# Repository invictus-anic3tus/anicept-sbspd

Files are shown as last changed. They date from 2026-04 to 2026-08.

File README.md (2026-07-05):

<div align="center">

  <h1>The Anicept SBSPD</h1>

  title image

  <h3>By Anicetus</h3>

  <p display="inline">

  <a href="https://creativecommons.org/licenses/by-nc/4.0/">
    </a> <a href="https://hackclub.com/">
    
  </a>

  </p>

  <h4>The Self Built Solder Paste Dispenser! Able to be mounted onto just about any 3D printer, this device adds a holder for a solder paste syringe, fully replacing the need to buy a solder stencil.</h4>
</div>

<sub>This work is licensed under a
[Creative Commons Attribution-NonCommercial 4.0 International License](https://creativecommons.org/licenses/by-nc/4.0/).
</sub>

## About

Hi! I'm Anicetus, and I love 3D printers and making custom hardware. Some of my favorite hardware to make is custom PCBs, namely the [Anicept Tempus](https://github.com/invictus-anic3tus/tempus), which often use very tiny SMD parts. The common choice is to go buy a solder stencil, which allows solder paste to be spread onto the PCB and easily reflowed. But stencils can get _expensive_. And, of course, they can only be used for one specific PCB! If your project needs a redesign, that means you need a whole new stencil for it.

So I got to thinking. Way back when, all plastic parts were made with injection molding, which had the same problems as solder stencils do now: to make a different plastic part, you need a whole new mold, which is very expensive. Then they invented 3D printers. These devices move in all three dimensions to make almost _any_ plastic part you want--why shouldn't the stencil problem have the same solution?

Well, maybe there is a good reason that this isn't so widespread. In any case, I'm about to find out.

## Features

- A Nema 11 stepper motor for accurate and high-power control over the solder syringe
- An easy-to-use clamp/hinge system that holds everything tightly in place
- A magnet-based mounting system that's compatable with any 3D printer
- Only four different screws/nuts!
- A fully 3D printable case
- A compact form factor
- ... all this for $15!

## Assembly + Usage

Assembly video coming soon! For now, please reference the CAD design to see how everything fits together :)







SBSPD_Wiring

## Bill of Materials

| Part | Link | Price  | Notes |
|---|---|---|---|
| Nema 11 | https://www.aliexpress.us/item/2255799884723806.html | $5.58  | 11HS3410 |
| Motor Driver | https://www.aliexpress.us/item/3256805074646808.html | $0.99  | TMC2209 |
| M5x50 SHCS | https://www.aliexpress.us/item/2255800598515019.html | $0.99  | For plunger + hinge |
| M2.5x16 SHCS | https://www.aliexpress.us/item/2255800598515019.html | $0.99  | For motor + clamp |
| M5 Nut | https://www.aliexpress.us/item/2255800416538696.html | $0.99  | For hinge + gear |
| M2.5 Nut | https://www.aliexpress.us/item/2255800416538696.html | $0.99  | For clamp |
| Magnets | https://www.aliexpress.us/item/3256809809310037.html | $0.99  | 4x2mm - required over ten for the PCB-bed mount standoffs |
| Adhesive | https://www.aliexpress.us/item/3256809785876209.html | $0.99  | For attaching the mount to the 3D printer |
| Solder Paste | https://www.amazon.com/SMD291AX-REWORK-SOLDER-PASTE-CLEAN/dp/B0186IM0P0 | $14.99 | Any solder paste in Chip Quik's 5CC syringe |
| Sum | | $27.50 | |
| Grand Total  | | $29.77 | |
| Paste Owned: | | $13.54 | |

## Contributing

<sub>aha somebody wishes to help me i see</sub>

If you'd like to request changes, suggest additions, or forcefully make me edit things, feel free to contact me via email (`me at anicetus dot dev`, preferred) or Discord (anic3tus).

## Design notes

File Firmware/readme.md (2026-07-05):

# Firmware

This is the firmware for the Anicept SBSPD. Because I'm a hardware guy and not a software guy, this was made using Claude AI, but I manually reviewed it to ensure that it works.

Probably.

## File Structure

```
paste_dispenser/
├── main.py              # CLI — handles parse, blacklist run, info commands
├── pad_model.py         # Defines solder pads, contains main config
├── gerber_parser.py     # Converts top/bottom solder paste gerber file into a list of pads, checks for the priming point and blacklisted pads
├── toolpath.py          # Uses nearest-neighbor to sort pads, checks for pads that are too close
├── gcode_gen.py         # Converts pad x/y coords into gcode, generates dispensing commands
├── dispenser.py         # Initiates the dispenser TMC2209, contains functions to be controlled via Klipper
└── klipper_config.cfg   # Basic additional Klipper config
```

## Installation

First, download the `paste_dispenser` folder and add it to the RPi's root. Then, on the Pi, install pcb-tools, shapely, RPi.GPIO (probably already installed) and pytrinamic. Look through the base dispenser config in pad_model.py, and input any custom values. As I haven't built this yet myself (as of June 2026) these values are currently NOT correct. You will be able to edit this config when exporting the config .json file later, but it's a good idea to set constants here first.

Add the Klipper config to your configuration; I recommend reviewing the file first to make sure it lines up with your setup.

## Workflow

Note: the system accepts both .GTP and .GBP files. The former is for the top layer, the latter for the bottom.

### Gerber Parsing

First, run `python3 main.py parse [YOUR_GERBER_FILE].GTP --netlist [YOUR_NETLIST].net` to check out the paste layer, find pads, and write a config .json file in the folder. The netlist file is for detecting the first test point, which is by default the priming pad. If you don't have one, the biggest pad on the board is used as the fallback priming pad. This is useful if the largest pad is like a capcitor or something, but if it happens to just be a heatsink you probably don't wanna prime on it, since it'd attempt to fill the entire thing up.

Next, on a related note, you can blacklist any pads that you don't want solder on. This could be heatsinks, decorative pads, etc. To do this, run `python3 main.py blacklist [YOUR_GERBER_FILE].GTP --config [GENERATED_CONFIG_FILE].json`. It'll open the CLI, which allows you to select pads based on location (these coords are relative to the priming pad, so you can measure easily off of it. It'll show up as at 0, 0 in this CLI) and toggle their status.

Now you can edit the configuration. Open the json file to adjust the values as needed.

### Printing Files

To generate the gcode file, run the command `python3 main.py run [YOUR_GERBER_FILE].GTP --config [GENERATED_CONFIG_FILE].json`. Rename it to something descriptive of your project, upload it to your printer, and attach the PCB using magnets, a clamp (making sure that it does not interfere with the printhead), etc. Home all three axes of the printer. Now, employ one of the following options to account for the rotational skew of the PCB on the build plate:

1. Align the PCB by a straight edge - using a straight edge on the PCB (or, ideally, a corner between two straight edges), line the PCB up against the build plate's edge and hold it in place. Note that if you change the orientation of the PCB relative to its gerber files, you must rotate the gerber files likewise BEFORE PARSING!
2. 3D print a casing for the PCB - if the design has no readily accessible straight edges, you can 3D print a square casing around it to more easily align it to the build plate.
3. Add a skew guide to the PCB - you can add a horizontal line or two points on the same axis coordinate and jog the printhead along them, simultaneously manually adjusting the PCB rotation to align with them.

Whichever method you use, the next step is to attach the solder paste toolhead, which simply uses magnets to snap into place on the pre-installed mount. After doing so, use gcode commands or your Klipper interface to move the solder dispenser's tip on top of the priming test point. Center it as accurately as possible, because it'll set the course for the entire operation. To gauge the z distance, use the paper method to get a consistent drag resistance every time. Always make sure that you run the gcode file with the z axis in position: nearly touching the test pad, just a paper's width offset.

Finally, you can run the gcode!

### Operation Details

First, the printhead will lower to the priming height above the priming pad and dispenses some solder to prime the tip. It then retracts, raises, and deposits paste on every pad in order of proximity. Finally, it uses an absolute move command to park and conclude the process.

## Config Reference & Tuning Tips

Sample configuration file:

```
{
  "gerber_file":  "/path/to/gerber.GTP",
  "netlist_file": "/path/to/netlist.net",

  "priming_pad": { "x": 12.4, "y": 8.7 },

  "z_offsets": {
    "travel":   5.0,
    "dispense": -0.05
  },

  "dispenser": {
    "prime_volume_ul": 3.0,
    "dot_volume_ul":   2.0,
    "drag_ul_per_mm":  1.0,
    "retract_mm":      0.15,
    "deretract_mm":    0.15,
    "syringe_id_mm":   5.5,
    "dispenser_hz":    300.0
  },

  "dwell_ms": {
    "prime": 500,
    "dot":   150
  },

  "speeds": {
    "travel":   3000.0,
    "dispense": 500.0
  },

  "blacklist": [
    { "x": 45.2, "y": 23.1, "label": "heatsink" }
  ],

  "park":        { "x": 0.0, "y": 0.0, "z": 50.0 },
  "klipper_cmd": "dispense"
}
```

| Field | Description |
|---|---|
| `priming_pad` | The X/Y coordinates of your priming test point |
| `z_offsets.travel` | How far in mm the dispenser should move up while travelling |
| `z_offsets.dispense` | The Z coordinate at dispensing. This controls the "squish"; you should tune it first |
| `dispenser.dot_volume_ul` | Volume dispensed for a dot. Tune this to accurately fill the pad |
| `dispenser.drag_ul_per_mm` | Volume per mm dispensed for a drag. Tune this to accurately fill the pad |
| `dispenser.retract_mm` | Distance retracted. Increase if paste oozes |
| `dispenser.deretract_mm` | Distance deretracted. Increase if the beginning of the pad is light |
| `dispenser.syringe_id_mm` | Inner diameter of the syringe barrel |
| `dispenser.dispenser_hz` | The motor's step rate: lower for torque and pressure spike handling, increase for speed |
| `dwell_ms.prime` | Millisecond wait time after priming. Increase if paste needs more flowing time |
| `dwell_ms.dot` | Millisecond wait time after each dot & before retract. Increase if paste needs more flowing time |
| `speeds.travel` | Printer travel speed in mm/min |
| `speeds.dispense` | Printer drag speed in mm/min. Decrease for more paste per mm, and vice versa  |
| `blacklist` | X/Y coordinates and label for ignored solder pads |
| `park` | Absolute position the toolhead moves to after the run completes |
| `klipper_cmd` | Name of the gcode_shell_command |

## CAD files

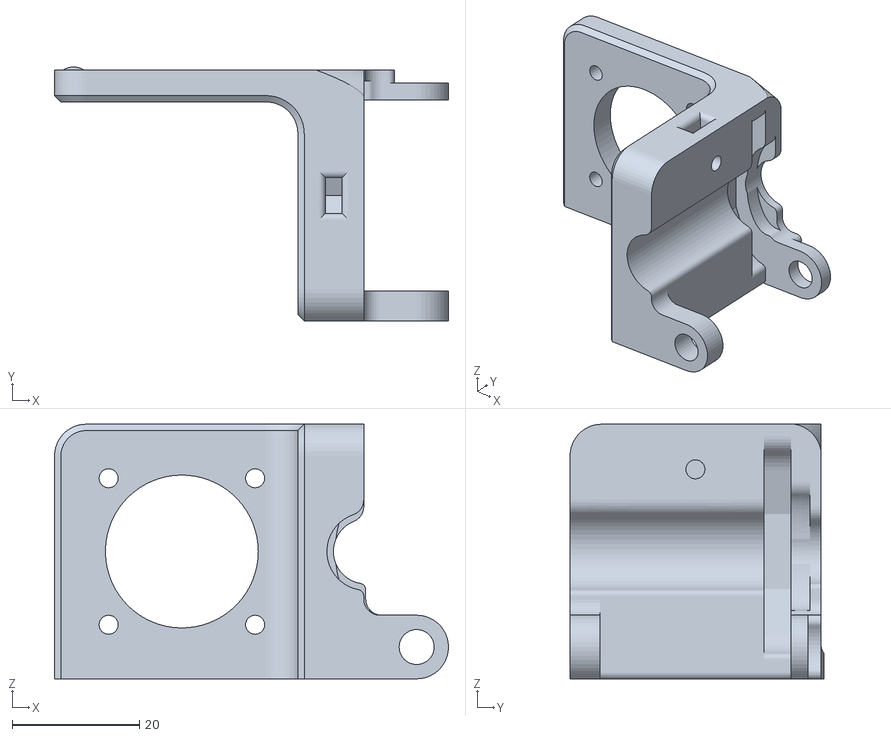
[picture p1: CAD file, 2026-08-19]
CAD/3D Print/Main_Body.stl
61.9 x 39.9 x 40.0

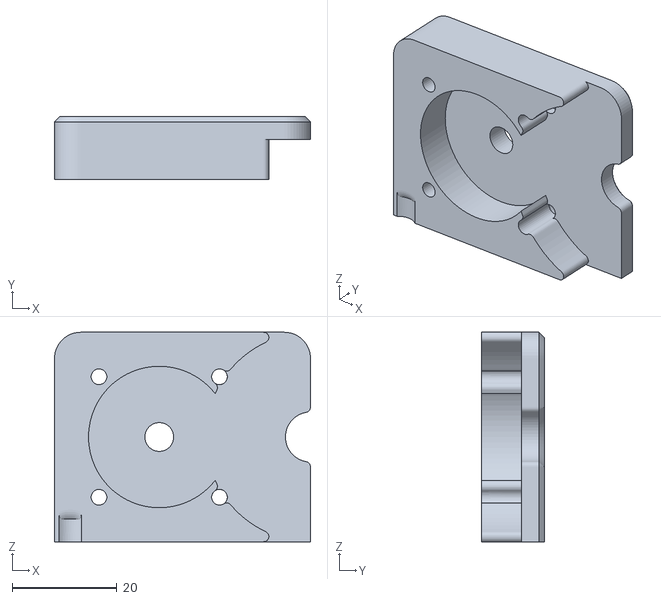
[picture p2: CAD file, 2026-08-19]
CAD/3D Print/Top.stl
48.9 x 12.0 x 40.0

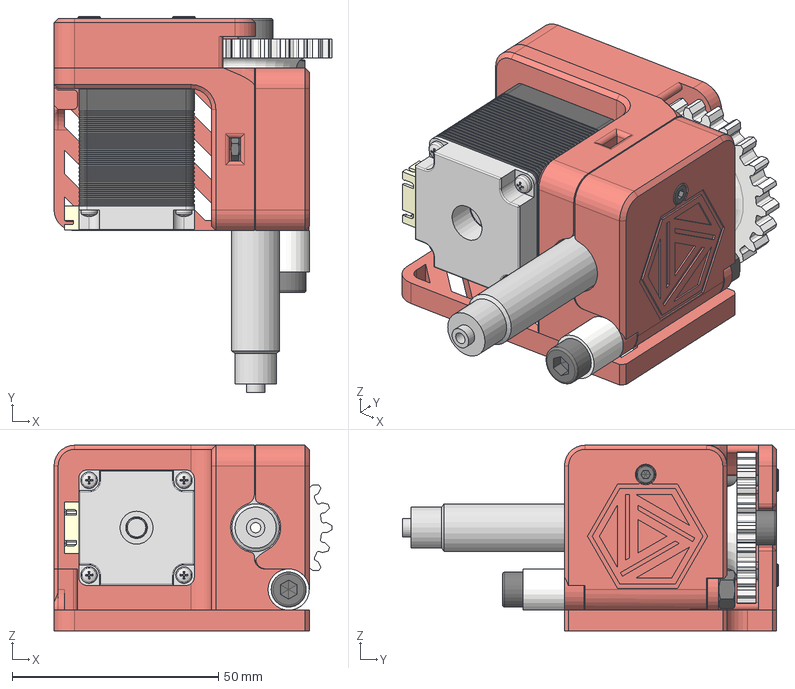
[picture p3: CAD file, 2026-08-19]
CAD/Self Built Solder Paste Dispenser.step
67.4 x 91.1 x 45.0 mm
Nema11 Main Body
Axel
Motor Back Cover
B4B-XH-A (LF)(SN)
ANSI B18.6.7M - M2x0,4 x 2,5, CRPHMSTIM(1) x 4
Syringe
Clamp
DIN EN ISO 4762 - M2.5 x 16 Steel 12.9 Black
DIN 934 - M2.5 x 0.45 Stainless Steel A2-70 Black
Motor Gear
Syringe Gear
DIN 934 - M5 x 0.8 Stainless Steel A2-70 Black
DIN 934 - M5 x 0.8 Stainless Steel A2-70 Black_1
Hinge Spacer
DIN EN ISO 4762 - M5 x 50 Steel 12.9 Black x 2
Screw Stabilizer
Rubber Tip Insert
Top
Mount
DIN EN ISO 4762 - M3 x 16 Steel 12.9 Black x 4
Mount Magnets
Assembly Magnets
Plunger Stabilizer

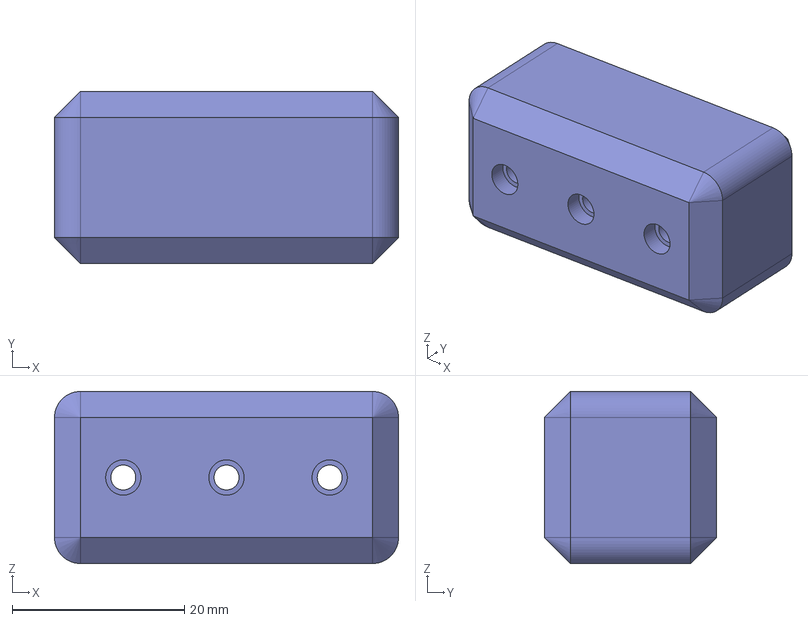
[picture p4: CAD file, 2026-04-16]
CAD/Bed Clamp.step
40.0 x 20.0 x 20.0 mm

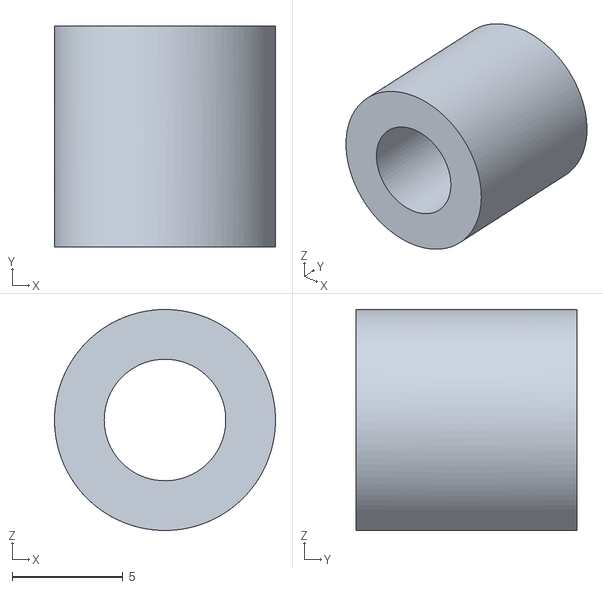
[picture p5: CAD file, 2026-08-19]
CAD/3D Print/Hinge_Spacer.stl
10.00 x 10.0 x 10.00

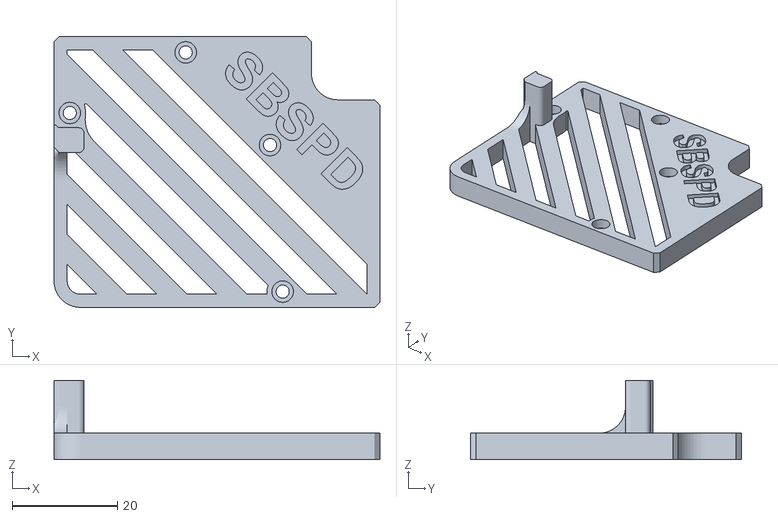
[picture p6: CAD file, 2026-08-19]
CAD/3D Print/Mount.stl
61.9 x 51.4 x 15.0

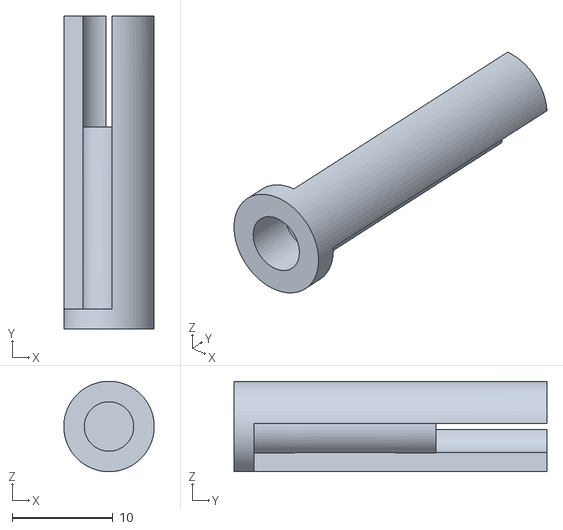
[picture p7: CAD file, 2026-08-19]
CAD/3D Print/Plunger.stl
8.96 x 31.0 x 8.96

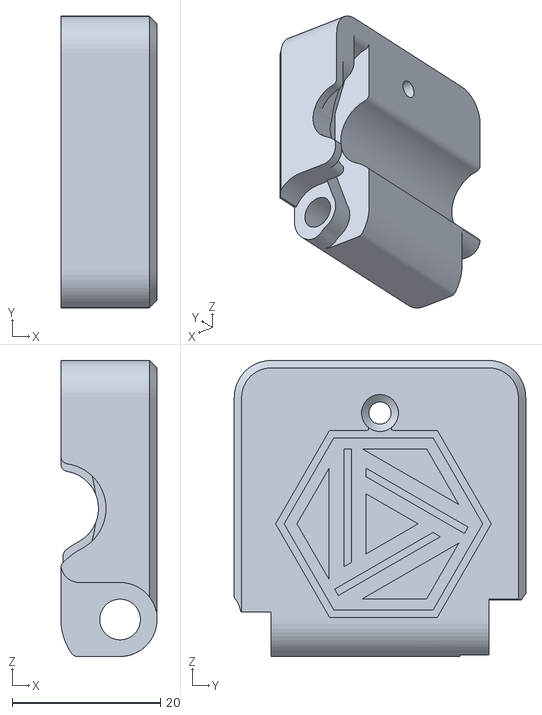
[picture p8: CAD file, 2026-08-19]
CAD/3D Print/Clamp.stl
13.0 x 39.4 x 40.0

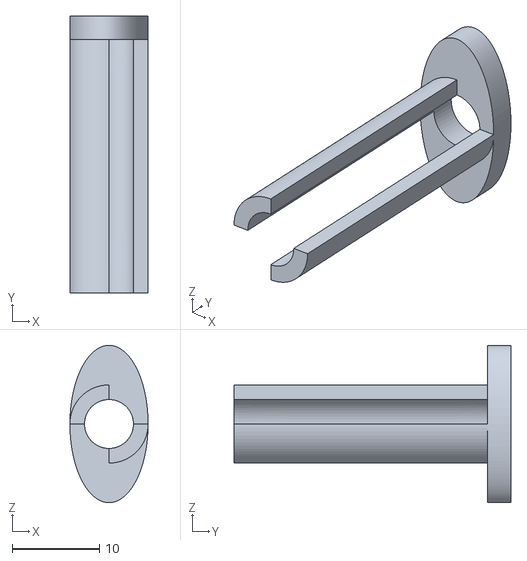
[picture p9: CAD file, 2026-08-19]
CAD/3D Print/Plunger_Stabilizer.stl
8.96 x 31.7 x 18.0

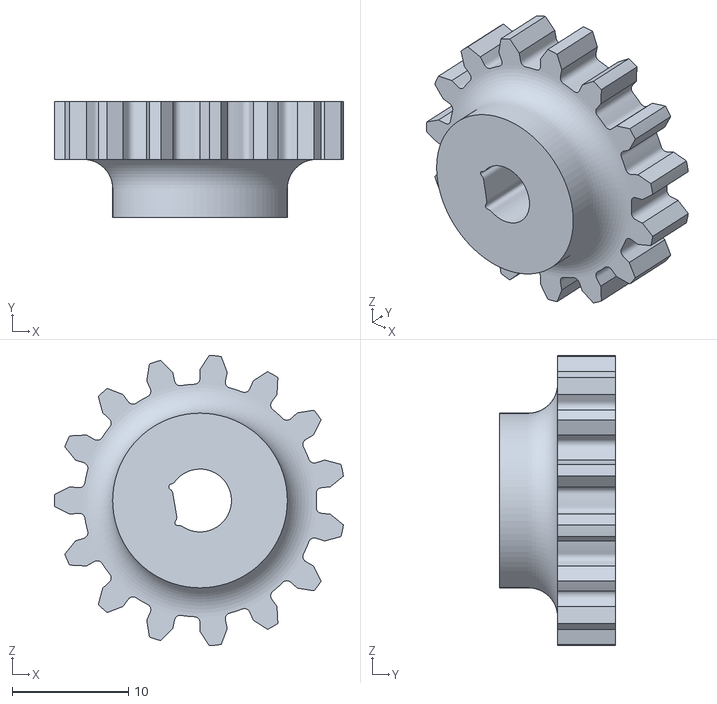
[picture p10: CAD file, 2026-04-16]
CAD/3D Print/Motor_Gear.stl
24.8 x 10.0 x 24.9

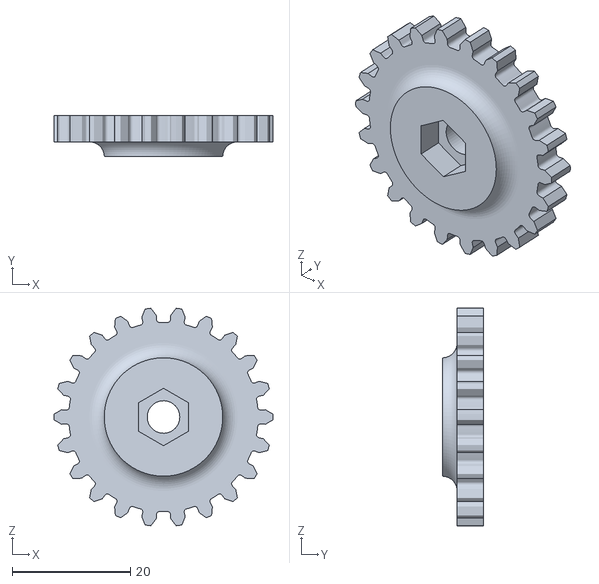
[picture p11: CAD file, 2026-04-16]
CAD/3D Print/Syringe_Gear.stl
37.0 x 7.00 x 36.7

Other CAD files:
CAD/3D Print/Bed_Clamp.stl
CAD/Bed Clamp.f3d
CAD/Self Built Solder Paste Dispenser.f3z

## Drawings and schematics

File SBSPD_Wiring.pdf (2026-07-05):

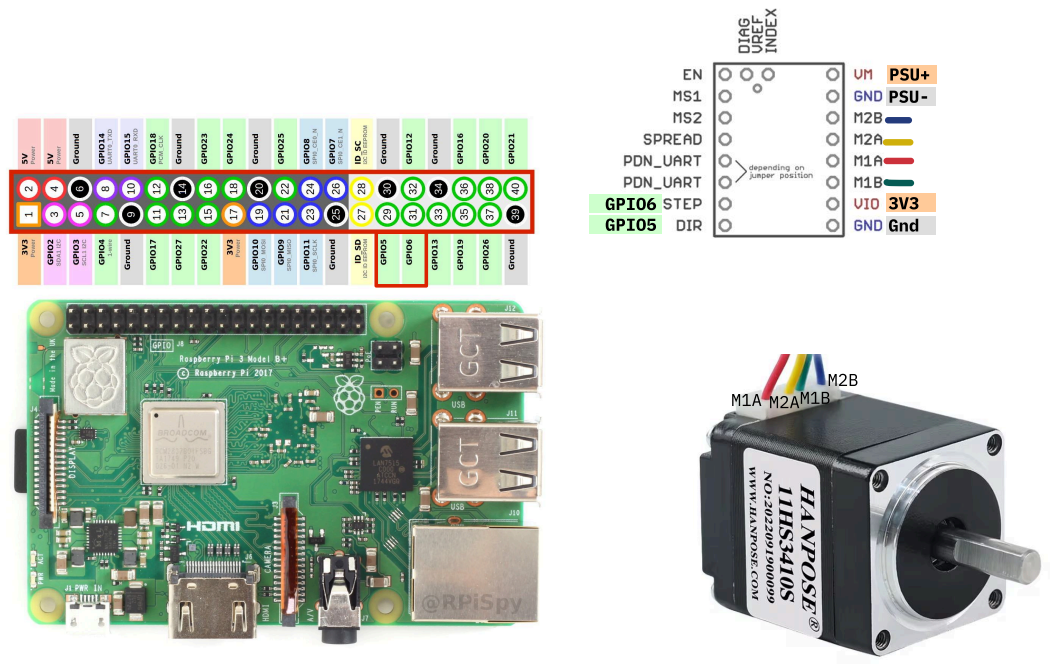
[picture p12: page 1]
PSU+; PSU-; GPIO6 GPIO5; Gnd

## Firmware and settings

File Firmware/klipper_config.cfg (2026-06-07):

# ─────────────────────────────────────────────────────────────────────────────────────────────────────────────────────────────
# Klipper config snippet — paste_dispenser
#
# Add this to your printer.cfg (or an [include paste_dispenser.cfg])
# ─────────────────────────────────────────────────────────────────────────────────────────────────────────────────────────────

# Shell command that calls the dispenser Python script.
# Adjust the path to wherever you cloned/copied the project.
[gcode_shell_command dispense]
command: python3 /home/pi/paste_dispenser/dispenser.py
timeout: 30
verbose: True

# Optional: a convenience macro so you can test from the Klipper console
[gcode_macro PASTE_PRIME]
description: Prime the paste extruder
gcode:
    RUN_SHELL_COMMAND CMD=dispense PARAMS="prime 3.0 200"

[gcode_macro PASTE_RETRACT]
description: Retract paste (anti-drool)
gcode:
    RUN_SHELL_COMMAND CMD=dispense PARAMS="retract 0.15 300"

[gcode_macro PASTE_DERETRACT]
description: Deretract paste before dispensing
gcode:
    RUN_SHELL_COMMAND CMD=dispense PARAMS="deretract 0.15 300"

# ─────────────────────────────────────────────────────────────────────────────────────────────────────────────────────────────
# Usage notes
# ─────────────────────────────────────────────────────────────────────────────────────────────────────────────────────────────
#
# 1. Enable gcode_shell_command in moonraker.conf if not already:
#       [update_manager klipper-extra-scripts]
#       ...
#    (Most Mainsail/Fluidd installs include this via KIAUH)
#
# 2. Make dispenser.py executable:
#       chmod +x /home/pi/paste_dispenser/dispenser.py
#
# 3. Test from Klipper console:
#       RUN_SHELL_COMMAND CMD=dispense PARAMS="dispense 2.0 300"
#
# 4. The generated .gcode file uses relative positioning (G91) throughout.
#    Before running it:
#       a. G28  (home all axes)
#       b. Attach paste extruder toolhead manually
#       c. Use the tip along a PCB straight edge (or trace, silkscreen line, etc.) to ensure the PCB is not skewed
#       d. Jog tip to the priming test point on the PCB
#       e. Start the .gcode file — do NOT re-home after step (c)
#
# ─────────────────────────────────────────────────────────────────────────────────────────────────────────────────────────────

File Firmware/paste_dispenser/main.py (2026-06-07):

"""
main.py
Orchestrates the full paste-dispenser pipeline:

    python3 main.py parse     <gerber> [--netlist <file>] [--config <out.json>]
    python3 main.py blacklist <gerber> --config <cfg.json>
    python3 main.py run       <gerber> --config <cfg.json> [--output <out.gcode>]
    python3 main.py info      <gerber>
"""

from __future__ import annotations
import argparse
import os
import sys

from pad_model       import DispenserConfig, BlacklistEntry
from gerber_parser   import parse_paste_layer, apply_origin_shift
from toolpath        import nearest_neighbour, estimate_travel_distance, check_dense_pads
from gcode_gen       import generate_gcode


# ── Commands ──────────────────────────────────────────────────────────────────

def cmd_parse(args):
    """
    Parse a Gerber file, detect priming pad, generate a config template.
    The user edits the generated .json before running `run`.
    """
    pads, priming = parse_paste_layer(
        args.gerber,
        netlist_path=args.netlist or "",
    )

    if not pads:
        print("[error] No pads found in Gerber file.")
        sys.exit(1)

    px, py = priming if priming else (pads[0].center_x, pads[0].center_y)

    cfg = DispenserConfig.template(
        gerber_file=os.path.abspath(args.gerber),
        priming_x=px,
        priming_y=py,
    )
    if args.netlist:
        cfg.netlist_file = os.path.abspath(args.netlist)

    config_path = args.config or (os.path.splitext(args.gerber)[0] + "_config.json")
    cfg.save(config_path)

    print()
    print("─" * 55)
    print(f"  Config template saved → {config_path}")
    print(f"  Priming pad detected  → ({px:.3f}, {py:.3f})")
    print()
    print("  Next steps:")
    print("    1. Review / adjust priming pad in config if needed")
    print("    2. Run blacklist command to mark pads to skip:")
    print(f"         python3 main.py blacklist {args.gerber} --config {config_path}")
    print("    3. Tune Z offsets, volumes, and speeds in config")
    print(f"    4. python3 main.py run {args.gerber} --config {config_path}")
    print("─" * 55)


def cmd_blacklist(args):
    """
    Interactively review all pads and toggle blacklist entries,
    then save the updated config. No manual coordinate entry needed.
    """
    cfg = DispenserConfig.load(args.config)
    gerber_path = args.gerber or cfg.gerber_file

    pads, _ = parse_paste_layer(gerber_path, blacklist=cfg.blacklist)
    if not pads:
        print("[error] No pads found.")
        sys.exit(1)

    # Shift to origin so coordinates match what G-code will use
    apply_origin_shift(pads, cfg.priming_x, cfg.priming_y)

    # Sort by area descending — large pads (heatsinks etc.) float to top
    sorted_pads = sorted(pads, key=lambda p: p.area, reverse=True)

    print()
    print("  Pads sorted by area — largest first (most likely blacklist candidates).")
    print("  Type pad number(s) to toggle blacklist on/off.")
    print("  Blacklisted pads are marked [X] and will be skipped in G-code.")
    print()

    while True:
        # Print table
        print(f"  {'#':>4}  {'':3}  {'Type':4}  {'Center X':>9}  {'Center Y':>9}"
              f"  {'W':>6}  {'H':>6}  {'Area mm²':>8}  Label")
        print("  " + "─" * 72)
        for i, p in enumerate(sorted_pads):
            status = "[X]" if p.blacklisted else "   "
            ptype  = "DRAG" if p.pad_type.name == "DRAG" else "DOT "
            label  = p.label or ""
            print(f"  {i+1:>4}  {status}  {ptype}  "
                  f"{p.center_x:>9.3f}  {p.center_y:>9.3f}  "
                  f"{p.width:>6.3f}  {p.height:>6.3f}  "
                  f"{p.area:>8.4f}  {label}")

        print()
        raw = input("  Toggle pad(s) [e.g. 1  or  1,3,5], or Enter to save: ").strip()
        if not raw:
            break

        for token in raw.split(","):
            token = token.strip()
            if not token.isdigit():
                print(f"  [skip] not a number: {token!r}")
                continue
            idx = int(token) - 1
            if not (0 <= idx < len(sorted_pads)):
                print(f"  [skip] out of range: {token}")
                continue
            p = sorted_pads[idx]
            p.blacklisted = not p.blacklisted
            if p.blacklisted:
                label = input(f"  Label for pad {idx+1} (e.g. 'heatsink', or Enter to skip): ").strip()
                p.label = label or ""
                print(f"  → Blacklisted pad {idx+1}  {p}")
            else:
                p.label = ""
                print(f"  → Removed from blacklist: pad {idx+1}  {p}")
        print()

    # Rebuild blacklist — un-shift coordinates back to original Gerber space
    cfg.blacklist = [
        BlacklistEntry(
            x     = p.center_x + cfg.priming_x,
            y     = p.center_y + cfg.priming_y,
            label = p.label,
        )
        for p in pads if p.blacklisted
    ]

    cfg.save(args.config)
    active = sum(1 for p in pads if not p.blacklisted)
    bl     = len(cfg.blacklist)
    print(f"\n  Saved — {bl} blacklisted, {active} active pad(s).\n")


def cmd_run(args):
    """
    Load config, parse Gerber with blacklist applied, sort toolpath,
    generate G-code file.
    """
    if not args.config:
        print("[error] --config <cfg.json> is required for the run command.")
        sys.exit(1)

    cfg = DispenserConfig.load(args.config)

    gerber_path = args.gerber or cfg.gerber_file
    if not gerber_path or not os.path.exists(gerber_path):
        print(f"[error] Gerber file not found: {gerber_path}")
        sys.exit(1)

    pads, _ = parse_paste_layer(
        gerber_path,
        netlist_path=cfg.netlist_file,
        blacklist=cfg.blacklist,
    )

    if not pads:
        print("[error] No pads parsed.")
        sys.exit(1)

    print(f"[info] Origin → priming pad ({cfg.priming_x:.3f}, {cfg.priming_y:.3f})")
    apply_origin_shift(pads, cfg.priming_x, cfg.priming_y)

    ordered = nearest_neighbour(pads, start_x=0.0, start_y=0.0)
    dist    = estimate_travel_distance(ordered)
    print(f"[info] Toolpath: {len(ordered)} pads, ~{dist:.1f}mm total travel")

    dense = check_dense_pads(pads)
    if dense:
        print(f"[warn] {len(dense)} closely-spaced pad pair(s) — review for bridging risk:")
        for a, b in dense[:5]:
            print(f"         ({a.center_x:.2f},{a.center_y:.2f}) ↔ "
                  f"({b.center_x:.2f},{b.center_y:.2f})")

    out_path = args.output or (os.path.splitext(gerber_path)[0] + "_paste.gcode")
    generate_gcode(ordered, cfg, out_path)

    print()
    print("─" * 55)
    print(f"  G-code ready → {out_path}")
    print()
    print("  To run on printer:")
    print("    1. Home printer (G28)")
    print("    2. Attach solder paste extruder")
    print("    3. Jog tip to priming test point")
    print("    4. Upload and start the G-code file")
    print("─" * 55)


def cmd_info(args):
    """Print a summary of pads found in the Gerber file."""
    from pad_model import PadType

    pads, priming = parse_paste_layer(args.gerber)
    if not pads:
        print("No pads found.")
        return

    dots  = sum(1 for p in pads if p.pad_type == PadType.DOT)
    drags = sum(1 for p in pads if p.pad_type == PadType.DRAG)

    areas = sorted(p.area for p in pads)
    avg   = sum(areas) / len(areas)

    print()
    print(f"  File    : {args.gerber}")
    print(f"  Pads    : {len(pads)}  ({dots} dot, {drags} drag)")
    print(f"  Area    : min={areas[0]:.3f}  avg={avg:.3f}  max={areas[-1]:.3f} mm²")
    if priming:
        print(f"  Priming : ({priming[0]:.3f}, {priming[1]:.3f})")
    print()
    print("  First 10 pads:")
    for p in pads[:10]:
        print(f"    {p}")


# ── CLI ───────────────────────────────────────────────────────────────────────

def main():
    parser = argparse.ArgumentParser(
        description="Solder paste dispenser — Gerber to G-code pipeline"
    )
    sub = parser.add_subparsers(dest="command", required=True)

    # parse
    p_parse = sub.add_parser("parse", help="Parse Gerber + generate config template")
    p_parse.add_argument("gerber",                help="Gerber paste layer (.GTP / .GBP)")
    p_parse.add_argument("--netlist", default="", help="KiCad netlist for test-point detection")
    p_parse.add_argument("--config",  default="", help="Output config JSON path")

    # blacklist
    p_bl = sub.add_parser("blacklist", help="Interactively mark pads to skip")
    p_bl.add_argument("gerber", nargs="?", default="", help="Gerber paste layer (or use path in config)")
    p_bl.add_argument("--config", required=True, help="Config JSON to update")

    # run
    p_run = sub.add_parser("run", help="Generate G-code from Gerber + config")
    p_run.add_argument("gerber", nargs="?", default="", help="Gerber paste layer (or use path in config)")
    p_run.add_argument("--config",  required=True, help="Config JSON (from `parse` step)")
    p_run.add_argument("--output",  default="",    help="Output .gcode path")

    # info
    p_info = sub.add_parser("info", help="Summarise pads in a Gerber file")
    p_info.add_argument("gerber", help="Gerber paste layer")

    args = parser.parse_args()

    if   args.command == "parse":     cmd_parse(args)
    elif args.command == "blacklist": cmd_blacklist(args)
    elif args.command == "run":       cmd_run(args)
    elif args.command == "info":      cmd_info(args)


if __name__ == "__main__":
    main()

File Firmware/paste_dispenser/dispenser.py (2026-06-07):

"""
dispenser.py
RPi + TMC2209 solder paste dispenser motor controller.

Called by Klipper via gcode_shell_command:
    RUN_SHELL_COMMAND CMD=dispense PARAMS="dispense 5.0 300"

Supported commands:
    prime          <volume_ul> <speed_hz>
    dispense       <volume_ul> <speed_hz>
    dispense_drag  <dist_mm>   <speed_hz>   ← single blocking call for drag moves
    retract        <dist_mm>   <speed_hz>
    deretract      <dist_mm>   <speed_hz>
    move_mm        <dist_mm>   <speed_hz>
"""

from __future__ import annotations
import math
import sys
import time

try:
    import RPi.GPIO as GPIO
    MOCK = False
except ImportError:
    print("[warn] RPi.GPIO not available — running in mock mode")
    MOCK = True


# ── Pin config (edit to match your wiring) ────────────────────────────────────
STEP_PIN = 17
DIR_PIN  = 27
EN_PIN   = 22

# ── Mechanical config (edit to match your hardware) ───────────────────────────
MICROSTEPS       = 16
STEPS_PER_REV    = 200 * MICROSTEPS   # 200-step motor × 16 µsteps = 3200
GEAR_RATIO       = 5.0                # your gearbox ratio
LEAD_MM_PER_REV  = 1.0               # lead screw pitch in mm/rev
STEPS_PER_MM     = STEPS_PER_REV * GEAR_RATIO / LEAD_MM_PER_REV

SYRINGE_ID_MM    = 5.5               # inner diameter of syringe barrel (mm)


# ── GPIO wrapper (transparent mock when not on RPi) ───────────────────────────

class _GPIO:
    BCM  = "BCM"
    OUT  = "OUT"
    HIGH = 1
    LOW  = 0

    @staticmethod
    def setmode(m):
        if not MOCK: GPIO.setmode(GPIO.BCM)

    @staticmethod
    def setup(pin, mode):
        if not MOCK: GPIO.setup(pin, GPIO.OUT)

    @staticmethod
    def output(pin, val):
        if not MOCK: GPIO.output(pin, val)

    @staticmethod
    def cleanup():
        if not MOCK: GPIO.cleanup()


_gpio = _GPIO()


# ── Dispenser ─────────────────────────────────────────────────────────────────

class PasteDispenser:
    def __init__(self, syringe_id_mm: float = SYRINGE_ID_MM):
        self.syringe_id_mm = syringe_id_mm

        _gpio.setmode(_gpio.BCM)
        _gpio.setup(STEP_PIN, _gpio.OUT)
        _gpio.setup(DIR_PIN,  _gpio.OUT)
        _gpio.setup(EN_PIN,   _gpio.OUT)
        _gpio.output(EN_PIN, _gpio.HIGH)   # keep disabled until a move

        self._configure_driver()

    def _configure_driver(self):
        """
        Configure TMC2209 over UART on /dev/serial0.
        Runs on every startup (driver has no non-volatile memory).
        Skipped gracefully if pytrinamic is not installed.
        """
        try:
            from pytrinamic.connections import UartTmclInterface
            import pytrinamic.ic.TMC2209 as TMC2209_IC

            iface = UartTmclInterface("/dev/serial0", datarate=115200)
            drv   = TMC2209_IC(iface, address=0)
            drv.set_motor_driver_current(400)   # mA — match your NEMA 11 rating
            drv.CHOPCONF.mres = 4               # 16 microsteps
            drv.GCONF.en_spreadcycle = 0        # StealthChop for quiet/slow moves
            drv.SGTHRS = 50                     # StallGuard threshold (tune per paste)
            iface.close()
            print("[info] TMC2209 configured via UART")
        except Exception as e:
            print(f"[warn] TMC2209 UART config skipped: {e}")

    # ── Motor primitives ──────────────────────────────────────────────────────

    def _enable(self):
        _gpio.output(EN_PIN, _gpio.LOW)

    def _disable(self):
        _gpio.output(EN_PIN, _gpio.HIGH)

    def _step(self, delay_s: float):
        _gpio.output(STEP_PIN, _gpio.HIGH)
        time.sleep(delay_s / 2)
        _gpio.output(STEP_PIN, _gpio.LOW)
        time.sleep(delay_s / 2)

    def move_mm(self, dist_mm: float, speed_hz: float = 300.0):
        """
        Move plunger by dist_mm.
        Positive = extrude (push paste), negative = retract.
        Blocks until move is complete.
        """
        if dist_mm == 0:
            return

        steps   = int(abs(dist_mm) * STEPS_PER_MM)
        forward = dist_mm > 0
        delay   = 1.0 / max(speed_hz, 1.0)

        _gpio.output(DIR_PIN, _gpio.LOW if forward else _gpio.HIGH)

        if MOCK:
            direction = "extrude" if forward else "retract"
            print(f"  [mock] {direction} {abs(dist_mm):.3f}mm "
                  f"({steps} steps @ {speed_hz:.0f} Hz)")
            return

        self._enable()
        for _ in range(steps):
            self._step(delay)
        self._disable()

    def _volume_to_mm(self, volume_ul: float) -> float:
        """Convert a volume in µL to plunger travel in mm (1 µL = 1 mm³)."""
        area_mm2 = math.pi * (self.syringe_id_mm / 2) ** 2
        return volume_ul / area_mm2

    # ── High-level commands ───────────────────────────────────────────────────

    def prime(self, volume_ul: float = 3.0, speed_hz: float = 200.0):
        print(f"[cmd] prime {volume_ul} µL @ {speed_hz} Hz")
        self.move_mm(self._volume_to_mm(volume_ul), speed_hz)

    def dispense(self, volume_ul: float = 2.0, speed_hz: float = 300.0):
        print(f"[cmd] dispense {volume_ul} µL @ {speed_hz} Hz")
        self.move_mm(self._volume_to_mm(volume_ul), speed_hz)

    def dispense_drag(self, dist_mm: float, speed_hz: float = 300.0):
        """
        Extrude continuously for the duration of a drag move.
        dist_mm is the XY drag length; extrusion volume = dist_mm × drag_ul_per_mm
        (drag_ul_per_mm is baked into dist_mm by the G-code generator).
        Blocks until complete — safe to call from a single shell command.
        """
        print(f"[cmd] dispense_drag {dist_mm:.3f} mm @ {speed_hz} Hz")
        self.move_mm(dist_mm, speed_hz)

    def retract(self, dist_mm: float = 0.15, speed_hz: float = 300.0):
        print(f"[cmd] retract {dist_mm} mm @ {speed_hz} Hz")
        self.move_mm(-abs(dist_mm), speed_hz)

    def deretract(self, dist_mm: float = 0.15, speed_hz: float = 300.0):
        print(f"[cmd] deretract {dist_mm} mm @ {speed_hz} Hz")
        self.move_mm(abs(dist_mm), speed_hz)

    def cleanup(self):
        _gpio.cleanup()


# ── CLI entry point ───────────────────────────────────────────────────────────

_COMMANDS = {
    "prime":         ("volume_ul", "speed_hz"),
    "dispense":      ("volume_ul", "speed_hz"),
    "dispense_drag": ("dist_mm",   "speed_hz"),
    "retract":       ("dist_mm",   "speed_hz"),
    "deretract":     ("dist_mm",   "speed_hz"),
    "move_mm":       ("dist_mm",   "speed_hz"),
}

def main():
    if len(sys.argv) < 2 or sys.argv[1] not in _COMMANDS:
        print("Usage: dispenser.py <command> [args...]")
        print("Commands:")
        for cmd, params in _COMMANDS.items():
            print(f"  {cmd:<16} {' '.join(params)}")
        sys.exit(1)

    cmd  = sys.argv[1]
    args = [float(a) for a in sys.argv[2:]]

    d = PasteDispenser()
    try:
        getattr(d, cmd)(*args)
    except TypeError as e:
        print(f"[error] Wrong arguments for {cmd!r}: {e}")
        sys.exit(1)
    finally:
        d.cleanup()
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

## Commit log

2026-04-16 Add CAD files
    [Clamp.stl, Main_Body.stl, Motor_Gear.stl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]
2026-04-16 Add logo to CAD files
    [Clamp.stl, SBSPD.f3z, SBSPD.step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]
2026-04-16 Update CAD files, create bed clamp
    [Bed Clamp.f3d, Bed Clamp.step, Bed Clamp.stl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]
2026-06-07 Add code, begin firmware readme
    [klipper_config.cfg]
2026-07-03 Update README.md bom to include solder paste
2026-07-05 Update firmware docs, add BOM.csv, update code
    [BOM.csv]
2026-07-05 Add wiring diagram
2026-08-19 Update 3D print files and full model files
    Added plunger stabilizer
    [Bed_Clamp.stl, Clamp.stl, Hinge_Spacer.stl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]
